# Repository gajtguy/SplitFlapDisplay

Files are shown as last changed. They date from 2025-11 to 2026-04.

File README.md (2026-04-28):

# Split-Flap Display

A modular, 3D-printed split-flap display controllable over RS485 from a Raspberry Pi. Each module holds 64 characters and modules can be chained together to build a display of any width.

**YouTube Build Video:** https://www.youtube.com/watch?v=-C8_AtxEEQc

---

## How It Works

Each module contains:
- A 3D-printed drum that holds 64 individual flaps (one per character)
- A stepper motor driving the drum through a gear train
- A Hall effect sensor for homing
- A custom driver PCB (ATtiny1616 + RS485 transceiver + ULN2003 stepper driver)

Modules communicate over a shared RS485 bus. A Raspberry Pi running a Python web interface sends commands over USB-RS485 to each module individually by address.

---

## Repository Structure

```
CAD/                              - 3D printable parts (Bambu Lab profiles included)
SplitFlapDriverATtiny1616 V2 KiCad/  - Driver PCB KiCad that I used in the video, for my build
SplitFlapDriverATtiny1616V3       - Updated Driver PCB KiCad project, which should be slightly cheaper to manufacture
SplitFlapBusBoard KiCad/          - Bus board KiCad project
SplitFlapFirmware/                - Arduino firmware for the PCBs
SplitFlap-RPI-FRONTEND/           - Raspberry Pi Python web frontend
Reference Docs/                   - Component datasheets
BOM.md                            - Bill of materials

**OnShape Model:** https://cad.onshape.com/documents/87c916b33ca5d6492b457485/w/b3e5f0f05f6619e6e7931347/e/582ef2164e20b0aa994708ab

---

## Parts List

See [BOM.md](BOM.md) for the complete bill of materials, broken into three sections:

- **PCB / Electronics** — all SMD components with JLCPCB part numbers for easy ordering
- **Module BOM** — 3D printed parts and hardware per module, with quantities scaled to 45 modules
- **Other Components** — system-level parts (Raspberry Pi, power supply, C14 connector, etc.)

---

## Ordering the PCB from JLCPCB

The driver board is designed to be ordered from JLCPCB with their PCB Assembly (PCBA) service so the SMD components arrive pre-soldered.

### Step 1 — Export Gerbers from KiCad

1. Open the project in `SplitFlapDriverATtiny1616 V2 KiCad/`
2. In KiCad PCB editor, go to **File → Fabrication Outputs → Gerbers**
3. Export to a folder, then zip the contents
4. Also export the drill file from the same menu

Alternatively, pre-exported Gerber and PCBA files are already be present in the KiCad project folder.

### Step 2 — Upload to JLCPCB

1. Go to [jlcpcb.com](https://jlcpcb.com) and click **Order Now**
2. Upload the Gerber zip file
3. Set your desired quantity (minimum 5)
4. Leave most settings at default; adjust PCB colour if desired

### Step 3 — Enable PCB Assembly (PCBA)

1. Toggle **PCB Assembly** on
2. Select **Standard PCBA** and set the assembly side to **Top Side**
3. Click **Confirm**

### Step 4 — Upload BOM and CPL Files

1. Upload the **BOM file** from the KiCad project folder — this maps component values to JLCPCB part numbers. The part numbers in `BOM.md` match what is in this file.
2. Upload the **CPL (Component Placement List)** file — this tells JLCPCB where each component sits on the board
3. Review the component matches on the next screen. All parts should auto-match using the C-numbers in [BOM.md](BOM.md). Confirm any that need manual review.

### Step 5 — Review and Order

1. Check the parts list — confirm quantities and part numbers match the [BOM.md](BOM.md) PCB section
2. Proceed through the review screens and place your order

> **Note:** A few through-hole parts (pin headers, JST connectors) are not included in PCBA. These are listed in the BOM and will need to be soldered by hand.

---

## 3D Printing

All printable files are in the `CAD/` folder. A Bambu Lab print profile is included in `CAD/64FlapsWithLetters/` for the flaps. Print the flaps in the correct colour for each character — see the video for details on the full 64-character set.

Parts per module:
- Enclosure Body, Right Cover, Left Cover
- Drum Body, Drum Cap
- Motor Gear, Center Gear, Gear Plate
- DIN Rail Mount, Wire Retainer
- 64 Flaps

---

## Firmware

Located in `SplitFlapFirmware/`. The firmware is Arduino-based and targets the ATtiny1616.

- Flash via UPDI programmer (see https://github.com/SpenceKonde/AVR-Guidance/blob/master/UPDI/jtag2updi.md if you need to make one)
- Each module needs a unique address (0–44) stored in EEPROM. Be sure to edit this between flashes.

---

## Frontend

Located in `SplitFlap-RPI-FRONTEND/`. A Python web interface running on a Raspberry Pi sends display commands over USB-RS485 at 115200 baud.

Need a USB-serial dongle. I used this one: https://www.adafruit.com/product/5994

---

## License

This project is licensed under [Creative Commons Attribution-NonCommercial-ShareAlike 4.0 International (CC BY-NC-SA 4.0)](https://creativecommons.org/licenses/by-nc-sa/4.0/).

You are free to share and adapt this project for non-commercial purposes, as long as you give appropriate credit to Adam G Makes and distribute any derivatives under the same license.

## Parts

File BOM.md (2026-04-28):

# Split-Flap Display BOM (Bill of Materials)

## Project Overview
A modular split-flap display system with 64 characters per module, controllable via RS485 from a Raspberry Pi. Designed by Adam G Makes.

**YouTube Video:** https://www.youtube.com/watch?v=-C8_AtxEEQc

**YouTube Channel:** https://www.youtube.com/@AdamGMakes

---

## PCB / Electronics BOM (Per Driver Board)

| Comment | Designator | Footprint | JLCPCB Part # |
|---|---|---|---|
| ATtiny1616-MNR | U1 | VQFN-20-1EP_3x3mm_P0.4mm_EP1.7x1.7mm | C507118 |
| 470n | C3, C8, C6, C2 | C_0603_1608Metric | C1623 |
| ULN2003ADR | U2 | SOIC-16W_5.3x10.2mm_P1.27mm | C7512 |
| HallEffect | J4 | PinHeader_1x03_P2.54mm_Vertical | C131339 |
| 100u | C1 | C_Elec_5x5.4 | C3347 |
| 100n | C7 | C_0603_1608Metric | C14663 |
| **0R** | R1 | R_0805_2012Metric | C17477 |
| LED | D1 | LED_0201_0603Metric | C3646923 |
| StepperConnector | J3 | JST_XH_B5B-XH-A_1x05_P2.50mm_Vertical | C157991 |
| SN65HVD72DR | U3 | SOIC-8_5.3x6.2mm_P1.27mm | C48125 |
| 60R | R2 | R_0201_0603Metric | C88957 |
| SPX3819M5-L-3-3 | U5 | SOT-23-5 | C20617301 |
| SPX3819M5-L-5-0 | U6 | SOT-23-5 | C20617302 |
| 10u | C5, C9, C4 | C_0603_1608Metric | C19702 |

Note: R1 is a 0 Ohm resistor.
---

## Module BOM

### 3D Printed Parts

| Part | Qty per Module | Qty (45 Modules) |
|---|---|---|
| Enclosure Body | 1 | 45 |
| Enclosure Right Cover | 1 | 45 |
| Enclosure Left Cover | 1 | 45 |
| Drum Body | 1 | 45 |
| Drum Cap | 1 | 45 |
| DIN Rail Mount | 1 | 45 |
| Motor Gear | 1 | 45 |
| Center Gear | 1 | 45 |
| Gear Plate | 1 | 45 |
| Wire Retainer | 1 | 45 |
| Flap | 64 | 2880 |

### Other Parts

| Part | Qty per Module | Qty (45 Modules) |
|---|---|---|
| M3 Nuts | 12 | 540 |
| M3 x 8mm Flat Head Screw | 4 | 180 |
| M3 x 30mm Flat Head Screw | 4 | 180 |
| M3 x 40mm Flat Head Screw | 4 | 180 |
| A3144 Hall Effect Sensor | 1 | 45 |
| **28BYJ-48 12V Stepper Motor**| 1 | 45 |
| Driver Board | 1 | 45 |
| Pogo Pins | 4 | 180 |
| 3x1mm N52 Magnet | 1 | 45 |
| 3-Pin JST Connector | 1 | 45 |

Note: Keep in mind, the driver boards are designed to be used with 12V motors, not the common 5V variety.

---

## Other Components (System-Level)

| Qty | Component | Notes |
|-----|---|---|
| 1 | Raspberry Pi | Controller |
| 1 | USB-RS485 Dongle | PC/RPi to RS485 adapter |
| 1 | 12V Power Supply | Module power |
| 1 | C14 Power Connector | Panel-mount inlet |
| 1 | Power Switch | Main power switch |
| 1 | C14 Power Cable | IEC mains cable |

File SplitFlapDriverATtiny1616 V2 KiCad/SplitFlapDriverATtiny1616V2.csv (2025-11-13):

Id | Designator | Footprint | Quantity | Designation | Supplier and ref
1 | J5 | PinHeader_1x06_P2.54mm_Vertical | 1 | Conn_01x06_Pin
2 | U1 | VQFN-20-1EP_3x3mm_P0.4mm_EP1.7x1.7mm | 1 | ATtiny1616-MNR
3 | C1 | C_Elec_5x5.4 | 1 | 100u
4 | U3 | SOIC-8_5.3x6.2mm_P1.27mm | 1 | SN65HVD72DR
5 | J1 | PinHeader_1x03_P2.54mm_Vertical | 1 | UPDI Programming
6 | C6,C2,C3 | C_0603_1608Metric | 3 | 470n
7 | C5,C4 | C_0603_1608Metric | 2 | 10u
8 | U5 | SOT-23-5 | 1 | SPX3819M5-L-3-3
9 | C7 | C_0603_1608Metric | 1 | 100n
10 | J4 | PinHeader_1x03_P2.54mm_Vertical | 1 | Hall Effect
11 | U2 | SOIC-16W_5.3x10.2mm_P1.27mm | 1 | ULN2003ADR
12 | R1 | R_0805_2012Metric | 1 | 0R
13 | J2 | PinHeader_1x04_P2.54mm_Vertical | 1 | BUS POGO
14 | J3 | JST_XH_B5B-XH-A_1x05_P2.50mm_Vertical | 1 | Stepper Connector

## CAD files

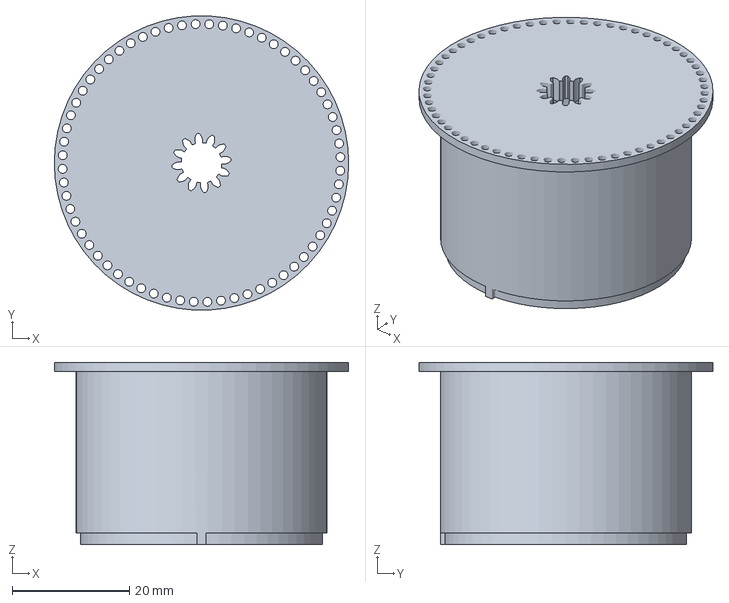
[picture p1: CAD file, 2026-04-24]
CAD/Character Drum - Character Drum Main.3mf
50.3 x 50.2 x 31.1 mm

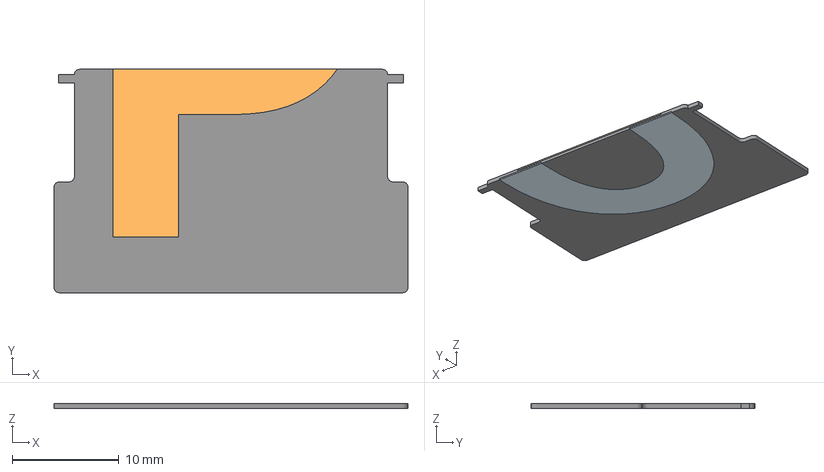
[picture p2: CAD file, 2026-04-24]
CAD/64FlapsWithLetters (parts and bambu print profile)/Flap16.3mf
33.1 x 20.9 x 0.48 mm
O_Top
Flap16
P_Bottom

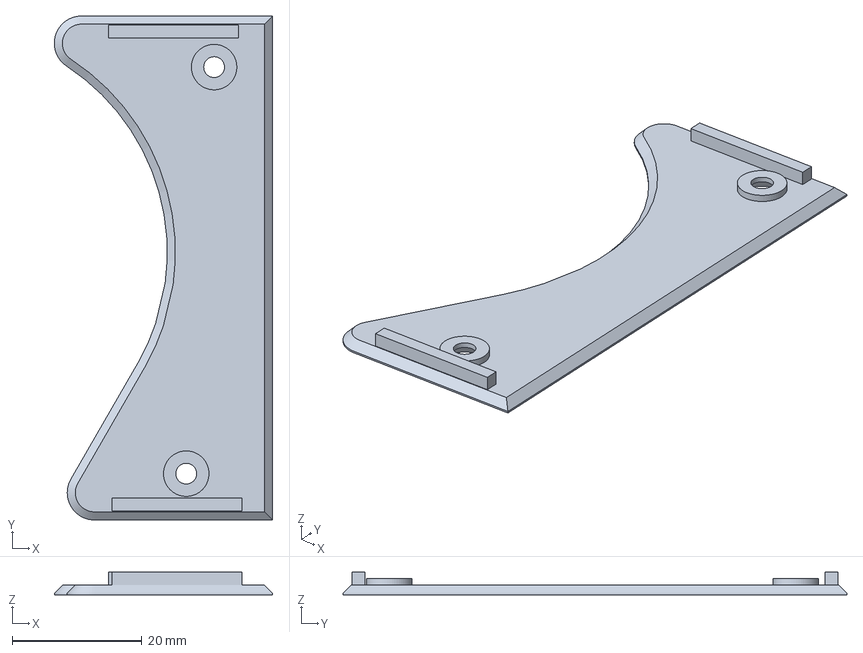
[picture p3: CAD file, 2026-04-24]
CAD/Module Enclosure - Enclosure Cover Bottom.3mf
33.6 x 77.6 x 3.50 mm

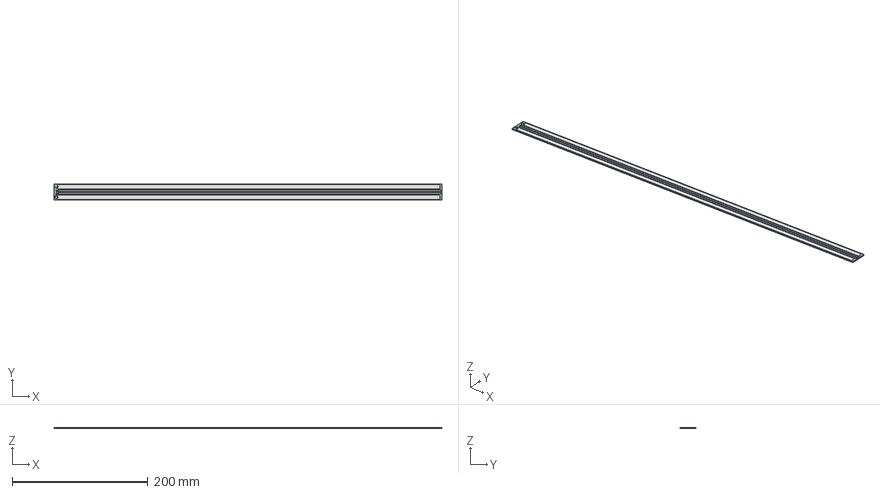
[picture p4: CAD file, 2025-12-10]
SplitFlapBusBoard KiCad/SplitFlapBusBoard.step
572.6 x 24.0 x 1.62 mm
SplitFlapBusBoard_pad
SplitFlapBusBoard_silkscreen
SplitFlapBusBoard_PCB

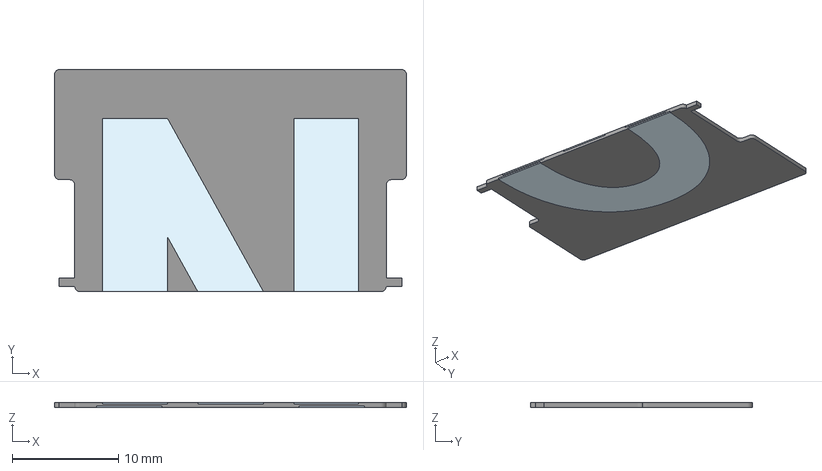
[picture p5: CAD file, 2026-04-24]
CAD/64FlapsWithLetters (parts and bambu print profile)/Flap15.3mf
33.1 x 20.9 x 0.48 mm
N_Top x 2
O_Bottom
Flap15

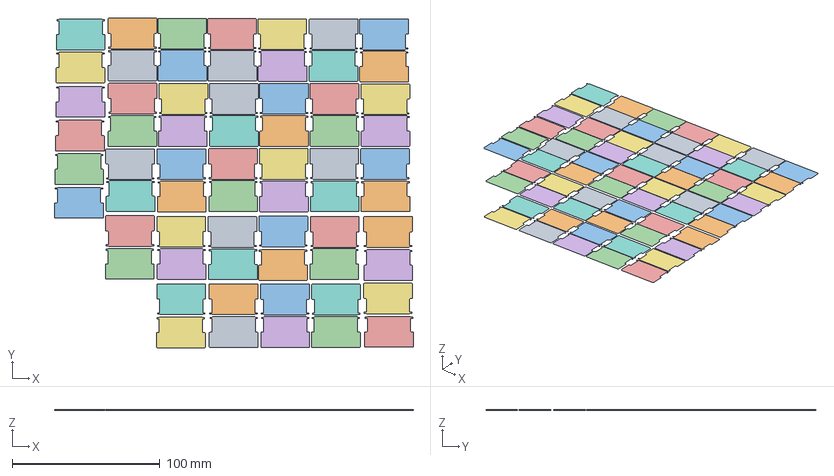
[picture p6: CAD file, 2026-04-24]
CAD/64FlapsWithLetters (parts and bambu print profile)/Flap1.3mf
243.2 x 223.3 x 0.48 mm
Flap10
Flap2
Flap3
Flap4
Flap6
Flap7
Flap8
Flap9
Flap1
Flap11
Flap12
Flap13
Flap14
Flap15
Flap16
Flap17
Flap18
Flap19
Flap20
Flap21
Flap22
Flap23
Flap24
Flap25
Flap26
Flap27
Flap28
Flap29
Flap30
Flap31
Flap32
Flap33
Flap34
Flap35
Flap36
Flap37
Flap38
Flap39
Flap40
Flap41
Flap42
Flap43
Flap44
Flap45
Flap46
Flap47
Flap49
Flap50
Flap51
Flap52
Flap54
Flap55
Flap57 x 7
Flap53
Flap58
Assembly
Flap5
Flap48

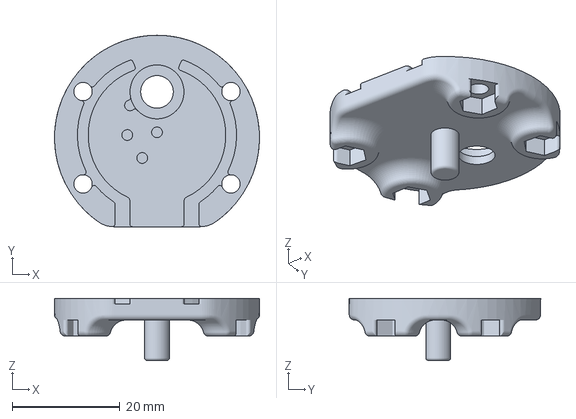
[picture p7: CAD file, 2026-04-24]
CAD/Gear Plate.3mf
38.0 x 35.5 x 11.5 mm

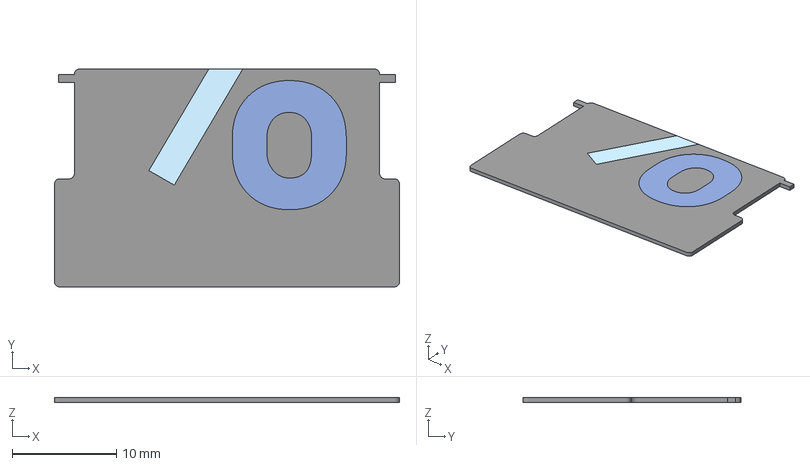
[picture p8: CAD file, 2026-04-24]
CAD/64FlapsWithLetters (parts and bambu print profile)/Flap50.3mf
33.1 x 20.9 x 0.48 mm
Colon_Top
Percent_Bottom x 2
Flap50

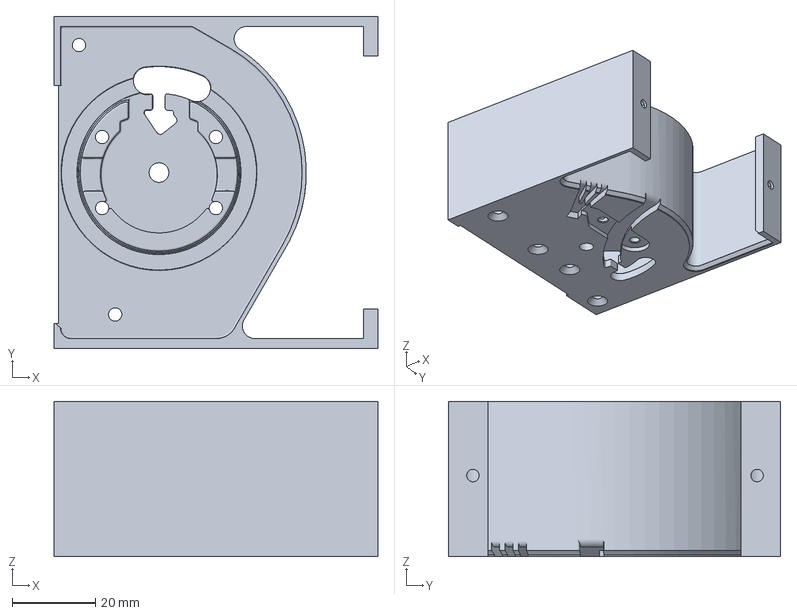
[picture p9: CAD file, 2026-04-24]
CAD/Module Enclosure - Enclosure.3mf
78.0 x 80.0 x 37.4 mm

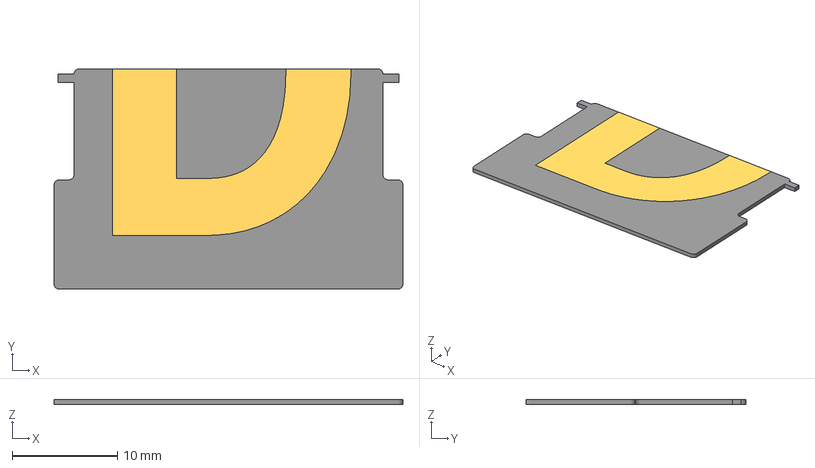
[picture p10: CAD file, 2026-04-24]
CAD/64FlapsWithLetters (parts and bambu print profile)/Flap4.3mf
33.1 x 20.9 x 0.48 mm
D_Bottom
C_Top
Flap 4

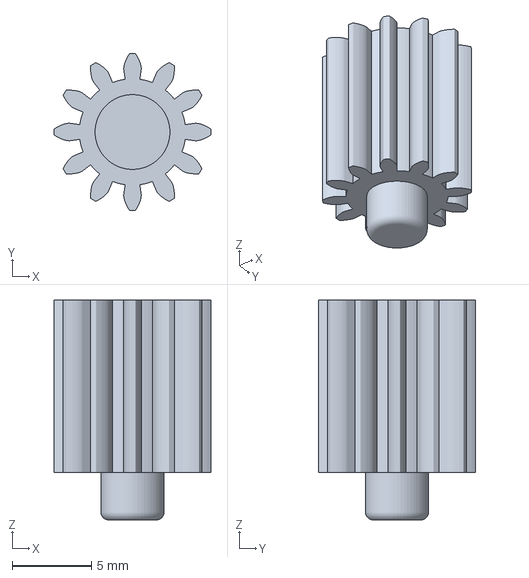
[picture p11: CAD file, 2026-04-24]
CAD/Center Gear.3mf
9.91 x 9.91 x 13.9 mm

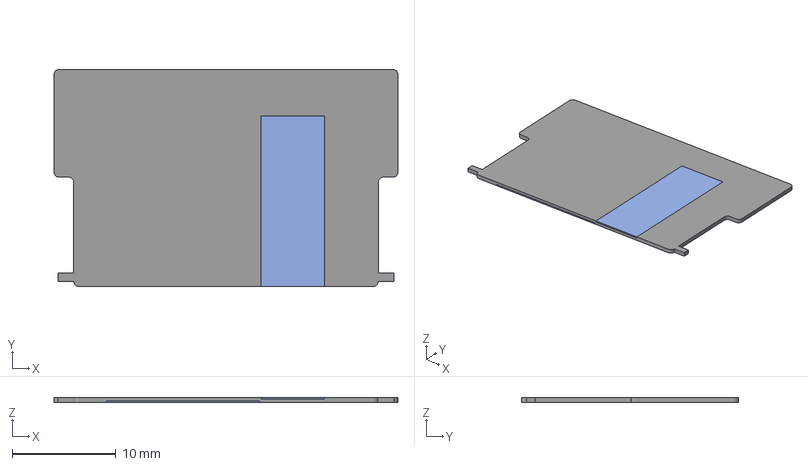
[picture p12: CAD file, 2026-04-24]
CAD/64FlapsWithLetters (parts and bambu print profile)/Flap11.3mf
33.1 x 20.9 x 0.48 mm
J_Top
K_Bottom
Flap11

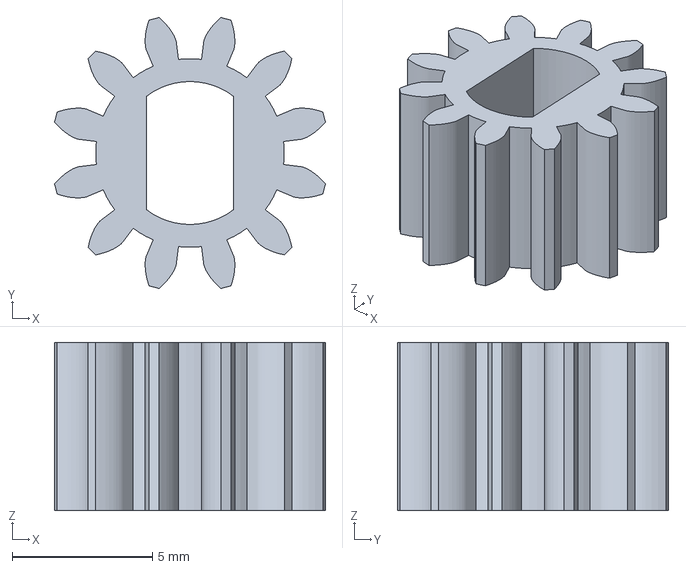
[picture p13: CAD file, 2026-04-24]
CAD/Motor Gear.3mf
9.67 x 9.67 x 6.00 mm

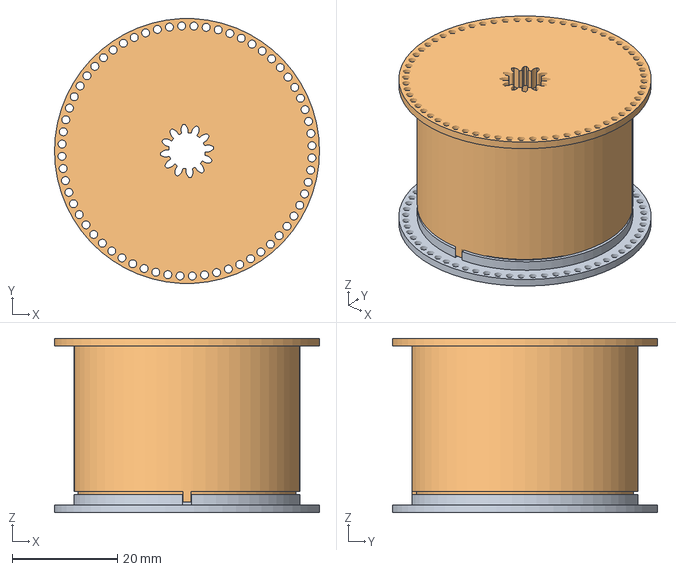
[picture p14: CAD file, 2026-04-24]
CAD/Character Drum.3mf
50.3 x 50.2 x 33.1 mm
Character Drum Lip
Character Drum Main

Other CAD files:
CAD/64FlapsWithLetters (parts and bambu print profile)/Flap21.3mf
CAD/64FlapsWithLetters (parts and bambu print profile)/Flap33.3mf
CAD/Character Drum - Character Drum Lip.3mf
CAD/64FlapsWithLetters (parts and bambu print profile)/Flap46.3mf
CAD/64FlapsWithLetters (parts and bambu print profile)/64FlapsPrintProfile.3mf
CAD/64FlapsWithLetters (parts and bambu print profile)/Flap10.3mf
CAD/64FlapsWithLetters (parts and bambu print profile)/Flap12.3mf
CAD/64FlapsWithLetters (parts and bambu print profile)/Flap13.3mf
CAD/64FlapsWithLetters (parts and bambu print profile)/Flap14.3mf
CAD/64FlapsWithLetters (parts and bambu print profile)/Flap17.3mf
CAD/64FlapsWithLetters (parts and bambu print profile)/Flap18.3mf
CAD/64FlapsWithLetters (parts and bambu print profile)/Flap19.3mf
CAD/64FlapsWithLetters (parts and bambu print profile)/Flap2.3mf
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

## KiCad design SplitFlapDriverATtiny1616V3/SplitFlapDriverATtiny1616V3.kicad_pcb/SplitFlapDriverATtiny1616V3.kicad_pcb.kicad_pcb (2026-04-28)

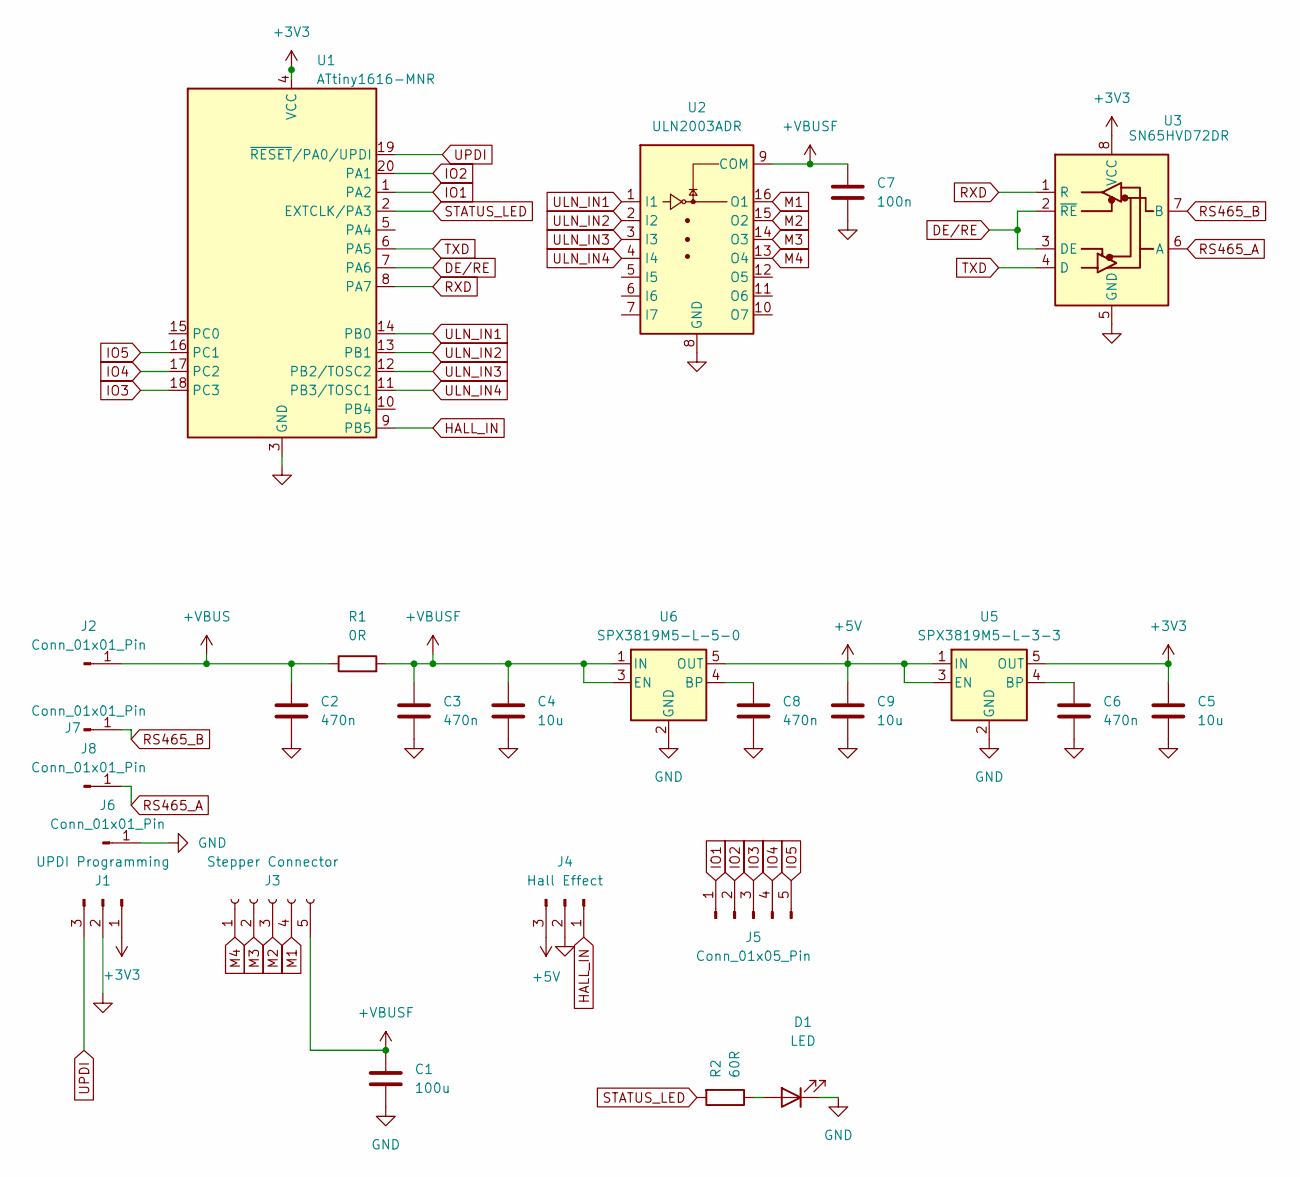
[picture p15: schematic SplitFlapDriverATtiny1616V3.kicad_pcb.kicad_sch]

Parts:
C1: 100u; C_Elec_5x5.4
C2, C3, C6, C8: 470n; C_0603_1608Metric
C4, C5, C9: 10u; C_0603_1608Metric
C7: 100n; C_0603_1608Metric
D1: LED; LED_0603_1608Metric
J1: UPDI Programming; PinHeader_1x03_P2.54mm_Vertical
J2, J6, J7, J8: Conn_01x01_Pin; PinHeader_1x01_P2.54mm_Vertical
J3: Stepper Connector; JST_XH_B5B-XH-A_1x05_P2.50mm_Vertical
J4: Hall Effect; JST_PH_B3B-PH-K_1x03_P2.00mm_Vertical
J5: Conn_01x05_Pin; PinHeader_1x05_P2.54mm_Vertical
R1: 0R; R_0805_2012Metric
R2: 60R; R_0603_1608Metric
U1: ATtiny1616-MNR; VQFN-20-1EP_3x3mm_P0.4mm_EP1.7x1.7mm; Manufacturer Part Number ATTINY1616-MNR; JLCPCB Part Number C507118
U2: ULN2003ADR; SOIC-16W_5.3x10.2mm_P1.27mm; Manufacturer Part Number ULN2003ADR; JLCPCB Part Number C7512
U3: SN65HVD72DR; SOIC-8_5.3x6.2mm_P1.27mm; Manufacturer Part Number SN65HVD72DR; JLCPCB Part Number C48125
U5: SPX3819M5-L-3-3; SOT-23-5
U6: SPX3819M5-L-5-0; SOT-23-5

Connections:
+3V3: C5.1, J1.1, U1.4 (VCC), U3.8 (VCC), U5.5 (OUT)
+5V: C9.1, J4.3, U5.1 (IN), U5.3 (EN), U6.5 (OUT)
+VBUS: C2.1, J2.1, R1.1
+VBUSF: C1.1, C3.1, C4.1, C7.1, J3.5, R1.2, U2.9 (COM), U6.1 (IN), U6.3 (EN)
DE/RE: U1.7 (PA6), U3.2 (~RE), U3.3 (DE)
GND: C1.2, C2.2, C3.2, C4.2, C5.2, C6.2, C7.2, C8.2, C9.2, D1.1 (K), J1.2, J4.2, J6.1, U1.3 (GND), U2.8 (GND), U3.5 (GND), U5.2 (GND), U6.2 (GND)
HALL_IN: J4.1, U1.9 (PB5)
IO1: J5.1, U1.1 (PA2)
IO2: J5.2, U1.20 (PA1)
IO3: J5.3, U1.18 (PC3)
IO4: J5.4, U1.17 (PC2)
IO5: J5.5, U1.16 (PC1)
M1: J3.4, U2.16 (O1)
M2: J3.3, U2.15 (O2)
M3: J3.2, U2.14 (O3)
M4: J3.1, U2.13 (O4)
unnamed: D1.2 (A), R2.1
unnamed: C6.1, U5.4 (BP)
unnamed: C8.1, U6.4 (BP)
RS465_A: J8.1, U3.6 (A)
RS465_B: J7.1, U3.7 (B)
RXD: U1.8 (PA7), U3.1 (R)
STATUS_LED: R2.2, U1.2 (EXTCLK/PA3)
TXD: U1.6 (PA5), U3.4 (D)
ULN_IN1: U1.14 (PB0), U2.1 (I1)
ULN_IN2: U1.13 (PB1), U2.2 (I2)
ULN_IN3: U1.12 (PB2/TOSC2), U2.3 (I3)
ULN_IN4: U1.11 (PB3/TOSC1), U2.4 (I4)
UPDI: J1.3, U1.19 (~RESET/PA0/UPDI)

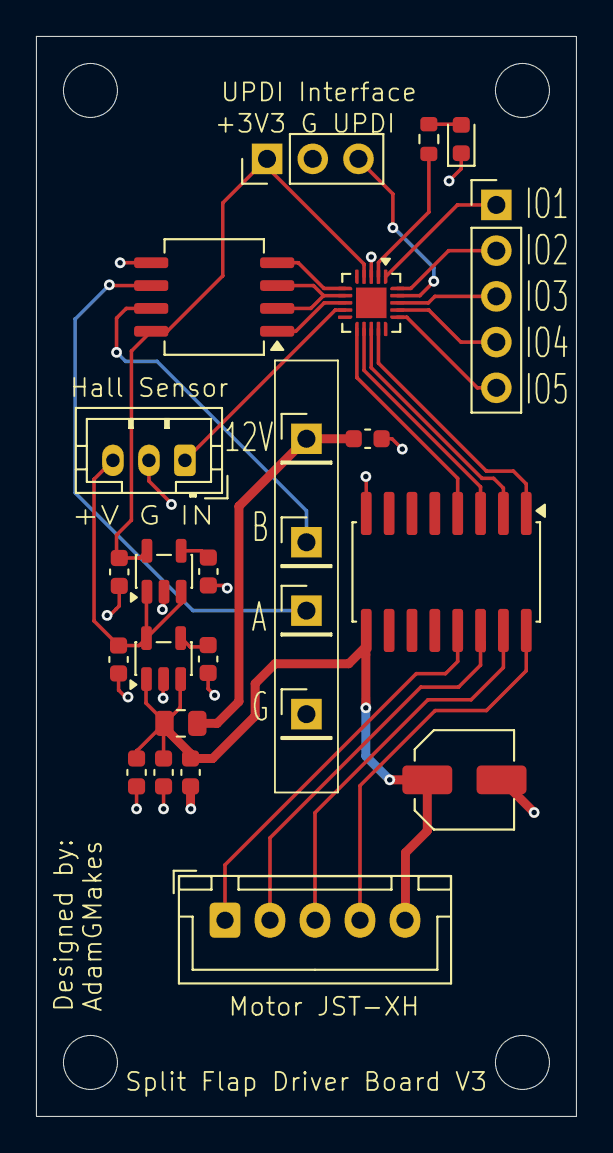
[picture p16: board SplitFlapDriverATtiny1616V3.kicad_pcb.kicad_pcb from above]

Board: 2 copper layers, 30.0 x 60.0 mm, 25 parts (0 on the bottom side), 29 nets.

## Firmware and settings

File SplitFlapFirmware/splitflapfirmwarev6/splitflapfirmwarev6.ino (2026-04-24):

#include <SoftwareSerial.h>
#include <EEPROM.h>

// ==========================================
//               CONFIGURATION
// ==========================================
// !!! CHANGE THIS FOR EACH MODULE TODAY !!!
const uint8_t HARDCODED_ID = 38; 

const String FLAP_CHARS = " ABCDEFGHIJKLMNOPQRSTUVWXYZ0123456789!@#$&()-+=;q:%'.,/?*roygbpw";

// EEPROM MAP
const int ADDR_INIT = 0;          // 1 byte  - Initialization flag
const int ADDR_HOME_OFFSET = 1;   // 2 bytes - Offset from magnet
const int ADDR_TOTAL_STEPS = 3;   // 2 bytes - Step length of reel
const int ADDR_MODULE_ID = 5;     // 1 byte  - The Module's Assigned ID (0-44)
const int ADDR_AUTO_HOME = 6;     // 1 byte  - Toggle for booting logic
const int ADDR_SAVED_POS = 7;     // 2 bytes - Last known step position
const int ADDR_SAVED_INDEX = 9;   // 1 byte  - Last known character index
const int ADDR_MAP_START = 12;    // 128 bytes - Exact character positions
const uint8_t INIT_VALUE = 0x5D;  // Magic number updated for new map

// Operating Variables
uint8_t moduleId = 255;
char idChars[2] = {'*', '*'};
bool autoHomeEnabled = true;

int stepsFromHallToZero = 2832;
int totalStepsPerRev = 4096;

// ==========================================
//              PIN DEFINITIONS
// ==========================================
const int RS485_RX = 3;
const int RS485_TX = 1;
const int RS485_DE = 2;

#define IN1 9
#define IN2 8
#define IN3 7
#define IN4 6
#define HALL_PIN 4

// ==========================================
//               GLOBALS
// ==========================================
SoftwareSerial rs485(RS485_RX, RS485_TX);

long currentStepPos = 0; 
int currentPhase = 0;
int parseState = 0; 
int currentFlapIndex = -1;
int tempIndex = -1;

const int stepDelay = 1;
String buffer = "";
unsigned long lastSerialTime = 0;

const uint8_t halfStepSequence[8][4] = {
  {1, 0, 0, 0}, {1, 1, 0, 0}, {0, 1, 0, 0}, {0, 1, 1, 0},
  {0, 0, 1, 0}, {0, 0, 1, 1}, {0, 0, 0, 1}, {1, 0, 0, 1}
};

// ==========================================
//             EEPROM FUNCTIONS
// ==========================================

void saveHomeOffset() { EEPROM.put(ADDR_HOME_OFFSET, stepsFromHallToZero); }
void saveTotalSteps() { EEPROM.put(ADDR_TOTAL_STEPS, totalStepsPerRev); }

void saveState() {
  if (!autoHomeEnabled) {
    EEPROM.put(ADDR_SAVED_POS, currentStepPos);
    EEPROM.put(ADDR_SAVED_INDEX, currentFlapIndex);
  }
}

void updateIdChars() {
  if(moduleId < 100) {
    idChars[0] = (moduleId / 10) + '0';
    idChars[1] = (moduleId % 10) + '0';
  }
}

void dumpEeprom() {
  // CRITICAL FIX: Give the Raspberry Pi's USB dongle 50ms to switch into listening mode
  delay(50); 
  digitalWrite(RS485_DE, HIGH);
  delay(10); 
  
  rs485.print("m");
  if(moduleId < 10) rs485.print("0");
  rs485.print(moduleId);
  rs485.print("d:");
  rs485.print(stepsFromHallToZero);
  rs485.print(":");
  rs485.print(totalStepsPerRev);
  rs485.print(":");
  
  bool first = true;
  for(int i=0; i<64; i++) {
    uint16_t pos = 0xFFFF;
    EEPROM.get(ADDR_MAP_START + (i * 2), pos);
    if(pos != 0xFFFF) {
      if(!first) rs485.print(",");
      rs485.print(i);
      rs485.print("=");
      rs485.print(pos);
      first = false;
    }
  }
  
  rs485.print("\n");
  delay(100); 
  digitalWrite(RS485_DE, LOW);
}

// ==========================================
//             MOTOR FUNCTIONS
// ==========================================

void applyStep(const uint8_t *step) {
  digitalWrite(IN1, step[0]);
  digitalWrite(IN2, step[1]);
  digitalWrite(IN3, step[2]); 
  digitalWrite(IN4, step[3]);
}

void stepBackward(int steps) {
  for (int k = 0; k < steps; k++) {
    bool hallNow = hallActive();
    static bool lastHallState = false;

    if (hallNow && !lastHallState) {
      currentStepPos = totalStepsPerRev - stepsFromHallToZero;
    }
    lastHallState = hallNow;

    currentPhase--;
    if (currentPhase < 0) {
      currentPhase = 7;
    }
    
    applyStep(halfStepSequence[currentPhase]);
    delay(stepDelay);
    
    currentStepPos++;
    if (currentStepPos >= totalStepsPerRev) {
      currentStepPos = 0;
    }
  }
}

void releaseMotor() {
  digitalWrite(IN1,0); digitalWrite(IN2,0); digitalWrite(IN3,0); digitalWrite(IN4,0);
}

bool hallActive() {
  return (digitalRead(HALL_PIN) == LOW);
}

// ==========================================
//             LOGIC FUNCTIONS
// ==========================================

void homeModule() {
  long safety = 0;
  while (!hallActive() && safety < (totalStepsPerRev + 500)) {
    stepBackward(1);
    safety++;
  }
  
  stepBackward(stepsFromHallToZero);
  currentStepPos = 0; 
  currentFlapIndex = 0;
  releaseMotor();
}

void calibrateModule() {
  long safety = 0;
  while (hallActive() && safety < 4000) {
    stepBackward(1);
    safety++;
    delay(5);
  }

  safety = 0;
  while (!hallActive() && safety < 5000) {
    stepBackward(1);
    safety++;
  }

  while (hallActive()) {
    stepBackward(1);
  }

  int measuredSteps = 0;
  while (!hallActive() && measuredSteps < 5000) {
    stepBackward(1);
    measuredSteps++;
  }

  while (hallActive()) {
    stepBackward(1);
    measuredSteps++;
  }

  // CRITICAL FIX: Wait for Pi to be ready
  delay(50);
  digitalWrite(RS485_DE, HIGH);
  delay(10); 
  
  rs485.print("m");
  if(moduleId < 100) {
    rs485.print(idChars[0]);
    rs485.print(idChars[1]);
  } else {
    rs485.print("XX");
  }
  rs485.print(":");
  rs485.print(measuredSteps);
  rs485.print("\n");
  
  delay(100); 
  digitalWrite(RS485_DE, LOW);
  
  totalStepsPerRev = measuredSteps;
  saveTotalSteps();
  homeModule();
  saveState();
}

void moveToChar(char targetChar) {
  int targetIndex = FLAP_CHARS.indexOf(targetChar);
  if (targetIndex == -1) return;
  if (currentFlapIndex == targetIndex) return; 
  
  if (currentFlapIndex == -1) {
    homeModule();
  }

  uint16_t mappedPos = 0xFFFF;
  EEPROM.get(ADDR_MAP_START + (targetIndex * 2), mappedPos);
  
  long targetStepPos;
  if (mappedPos != 0xFFFF) {
    targetStepPos = mappedPos;
  } else {
    targetStepPos = ((long)targetIndex * (long)totalStepsPerRev) / 64;
  }
  
  long stepsToMove = targetStepPos - currentStepPos;
  if (stepsToMove < 0) {
    stepsToMove += totalStepsPerRev;
  }
  
  while(stepsToMove > 0) {
    stepBackward(1);
    stepsToMove--;
  }

  releaseMotor();
  currentFlapIndex = targetIndex; 
  saveState(); 
}

// ==========================================
//              MAIN LOOP
// ==========================================

void setup() {
  pinMode(IN1, OUTPUT);
  pinMode(IN2, OUTPUT);
  pinMode(IN3, OUTPUT); 
  pinMode(IN4, OUTPUT);
  pinMode(HALL_PIN, INPUT_PULLUP);
  
  pinMode(RS485_DE, OUTPUT);
  digitalWrite(RS485_DE, LOW); 
  
  if (EEPROM.read(ADDR_INIT) == INIT_VALUE) {
    EEPROM.get(ADDR_HOME_OFFSET, stepsFromHallToZero);
    EEPROM.get(ADDR_TOTAL_STEPS, totalStepsPerRev);
    moduleId = EEPROM.read(ADDR_MODULE_ID);
    autoHomeEnabled = (EEPROM.read(ADDR_AUTO_HOME) == 1);
  } else {
    EEPROM.write(ADDR_INIT, INIT_VALUE);
    saveHomeOffset();
    saveTotalSteps();
    
    moduleId = HARDCODED_ID; 
    EEPROM.write(ADDR_MODULE_ID, moduleId);
    
    EEPROM.write(ADDR_AUTO_HOME, 1);
    autoHomeEnabled = true;
    
    for(int i=0; i<64; i++) {
      uint16_t empty = 0xFFFF;
      EEPROM.put(ADDR_MAP_START + (i*2), empty);
    }
  }

  updateIdChars();
  rs485.begin(9600);

  if (moduleId != 255) {
    delay(moduleId * 150); 
  }
  
  if (autoHomeEnabled) {
    homeModule();
    saveState();
  } else {
    EEPROM.get(ADDR_SAVED_POS, currentStepPos);
    if (currentStepPos >= totalStepsPerRev) currentStepPos = 0;
    currentFlapIndex = (int8_t)EEPROM.read(ADDR_SAVED_INDEX);
  }
}

void loop() {
  while (rs485.available()) {
    char c = rs485.read();
    lastSerialTime = millis();
    
    switch (parseState) {
      case 0: if (c == 'm') parseState = 1; break;
      case 1: if (c == idChars[0] || c == '*') parseState = 2; else parseState = 0; break;
      case 2: if (c == idChars[1] || c == '*') parseState = 3; else parseState = 0; break;
      
      case 3: 
        if (c == '-') parseState = 4;
        else if (c == 'h') { homeModule(); saveState(); parseState = 0; }
        else if (c == 'c') { calibrateModule(); parseState = 0; }
        else if (c == 'o') { buffer = ""; parseState = 5; }
        else if (c == 't') { buffer = ""; parseState = 6; }
        else if (c == 's') { buffer = ""; parseState = 7; } 
        else if (c == 'g') { buffer = ""; parseState = 8; } 
        else if (c == 'w') { buffer = ""; tempIndex = -1; parseState = 9; } 
        else if (c == 'i') { buffer = ""; parseState = 10; } 
        else if (c == 'a') { buffer = ""; parseState = 11; } 
        else if (c == 'd') { dumpEeprom(); parseState = 0; } 
        else if (c == 'e') { 
          for(int i=0; i<64; i++) {
            uint16_t empty = 0xFFFF;
            EEPROM.put(ADDR_MAP_START + (i*2), empty);
          }
          parseState = 0;
        } 
        else parseState = 0;
        break;
        
      case 4: moveToChar(c); parseState = 0; break;
      
      case 5: 
        if (isDigit(c)) buffer += c;
        else { 
          if (buffer.length()>0) {
            stepsFromHallToZero = buffer.toInt(); 
            saveHomeOffset();
          }
          parseState=0; 
        }
        break;
        
      case 6: 
        if (isDigit(c)) buffer += c;
        else { 
          if (buffer.length()>0) {
            totalStepsPerRev = buffer.toInt(); 
            saveTotalSteps();
          }
          parseState=0; 
        }
        break;
        
      case 7: 
        if (isDigit(c)) buffer += c;
        else { 
          if (buffer.length()>0) {
            int stepsToMove = buffer.toInt();
            stepBackward(stepsToMove);
            releaseMotor();
            stepsFromHallToZero += stepsToMove;
            saveHomeOffset();
          }
          parseState=0; 
        }
        break;
        
      case 8: 
        if (isDigit(c)) buffer += c;
        else {
          if (buffer.length() > 0) {
            long targetStep = buffer.toInt();
            long stepsToMove = targetStep - currentStepPos;
            if (stepsToMove < 0) stepsToMove += totalStepsPerRev;
            while(stepsToMove > 0) { stepBackward(1); stepsToMove--; }
            releaseMotor();
            currentFlapIndex = -2;
            saveState(); 
          }
          parseState = 0;
        }
        break;
        
      case 9: 
        if (c == ':') {
          tempIndex = buffer.toInt();
          buffer = "";
        } else if (isDigit(c)) {
          buffer += c;
        } else {
          if (buffer.length() > 0 && tempIndex != -1) {
            uint16_t pos = buffer.toInt();
            EEPROM.put(ADDR_MAP_START + (tempIndex * 2), pos);
          }
          parseState = 0;
        }
        break;

      case 10: 
        if (isDigit(c)) buffer += c;
        else {
          if (buffer.length() > 0) {
            moduleId = buffer.toInt();
            EEPROM.write(ADDR_MODULE_ID, moduleId);
            updateIdChars();
          }
          parseState = 0;
        }
        break;

      case 11: 
        if (isDigit(c)) buffer += c;
        else {
          if (buffer.length() > 0) {
            autoHomeEnabled = (buffer.toInt() == 1);
            EEPROM.write(ADDR_AUTO_HOME, autoHomeEnabled ? 1 : 0);
            saveState();
          }
          parseState = 0;
        }
        break;
    }
  }

  if ((parseState >= 5 && parseState <= 11) && (millis() - lastSerialTime > 50)) {
    if (buffer.length() > 0) {
      if (parseState == 5) { stepsFromHallToZero = buffer.toInt(); saveHomeOffset(); }
      if (parseState == 6) { totalStepsPerRev = buffer.toInt(); saveTotalSteps(); }
      if (parseState == 7) {
        int stepsToMove = buffer.toInt();
        stepBackward(stepsToMove);
        releaseMotor();
        stepsFromHallToZero += stepsToMove;
        saveHomeOffset();
      }
      if (parseState == 8) {
        long targetStep = buffer.toInt();
        long stepsToMove = targetStep - currentStepPos;
        if (stepsToMove < 0) stepsToMove += totalStepsPerRev;
        while(stepsToMove > 0) { stepBackward(1); stepsToMove--; }
        releaseMotor();
        currentFlapIndex = -2;
        saveState();
      }
      if (parseState == 9 && tempIndex != -1) {
        uint16_t pos = buffer.toInt();
        EEPROM.put(ADDR_MAP_START + (tempIndex * 2), pos);
      }
      if (parseState == 10) {
        moduleId = buffer.toInt();
        EEPROM.write(ADDR_MODULE_ID, moduleId);
        updateIdChars();
      }
      if (parseState == 11) {
        autoHomeEnabled = (buffer.toInt() == 1);
        EEPROM.write(ADDR_AUTO_HOME, autoHomeEnabled ? 1 : 0);
        saveState();
      }
    }
    parseState = 0;
  }
}

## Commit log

2025-11-13 Finished SplitFlapDriverATTiny1616 and sent for production
    [SplitFlapDriverATtiny1616V2-B_Cu.gbr, SplitFlapDriverATtiny1616V2-B_Mask.gbr, SplitFlapDriverATtiny1616V2-B_Paste.gbr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]
2025-12-10 Updated Hall Effect Header to JST-PH
    [SplitFlapBusBoard.step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]
2026-04-24 Cleaned up repo for sharing
    [64FlapsPrintProfile.3mf, Center Gear.3mf, Character Drum - Character Drum Lip.3mf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]
2026-04-25 Add BOM.md and README.md documentation
2026-04-28 Fix 5-module bus bar: replace with correct fabrication files
    The previous PR (#6) included the wrong KiCad project files. This
    removes those and replaces with the correct final Gerber/drill
    fabrication outputs for the 5-module bus bar design.
    [SplitFlapBusBoard-B_Cu.gbl, SplitFlapBusBoard-B_Mask.gbs, SplitFlapBusBoard-B_Paste.gbp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]
